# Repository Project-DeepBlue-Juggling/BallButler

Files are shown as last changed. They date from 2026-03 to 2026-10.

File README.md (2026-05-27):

# Ball Butler

An autonomous mobile robot that retrieves, stores, and throws balls to humans or other robots. Built around a 4-wheel swerve drive rover with onboard perception and a precision ball-throwing mechanism.

## Ball Butler V0 — Current State

The V0 thrower is **operational**. It accepts a target state (position and time) and executes a throw to hit that target. The mechanism was originally developed as part of the [Jugglebot](https://github.com/Project-DeepBlue-Juggling/Jugglebot) project and is now the foundation for the full Ball Butler system.

V0 is a deliberately simple, fixed-base machine — it predates the rover and is much less capable than the eventual mobile system described below. The version progression (V0 → V1+) is summarised in the comparison table at the end of this README.

**[CAD Model (Onshape)](https://cad.onshape.com/documents/b9a77ae444a199ae8fa4f0ef/w/58a21fff0c13c6549ee3697c/e/5104799fd810ebb1022a8885)**

### V0 mechanism (3 DoF, fixed-base)

- **Yaw** — unlimited rotation via a slip ring (no rewind required).
- **Pitch** — ~90° of travel: 0° = horizontal launch, 90° = vertical launch.
- **Linear axis** — a fast linear actuator provides the throwing motion itself.
- **Ball hopper** — manually loaded; a mechanical release drops one ball into the thrower each time a bumper is hit, so the thrower can reload itself once the hopper is filled.

### What works today

- Throwing to arbitrary commanded target states (position, time)
- Throw range ~2–4 m horizontal; launch height currently capped at ~50 cm by ceiling clearance during indoor testing
- Bumper-triggered single-ball release from the hopper
- Integration with Jugglebot as a ball-serving system

### What V0 does *not* do

- **No mobility** — V0 cannot move itself; it sits on a stand
- **No ball pickup** — the hopper is reloaded by hand
- **No catching** — V0 is throw-only. *No version of Ball Butler will catch balls.* The eventual rover-based system picks balls up off the ground after they land; it does not catch mid-air.

## Ball Butler V1+ — Planned System

The full Ball Butler is a standalone mobile robot — a substantial step up from V0 in every respect. V0 is essentially just the throwing subsystem on a stand; V1+ adds mobility, autonomous ball pickup, larger onboard storage, and a perception/navigation stack. V1+ comprises:

- **Rover platform** — 4-wheel swerve drive (8 DoF) for omnidirectional movement over sidewalks, curb cuts, grass, and gravel. Suspended wheels for terrain compliance.
- **Throwing mechanism** — evolved from the current thrower, mounted atop the rover.
- **Ball pickup** — a mostly-mechanical system to collect balls from the ground and feed them into onboard storage.
- **Ball storage** — onboard hopper carrying 5-10 balls (~70 mm, ~80 g each).
- **Navigation** — LiDAR and/or depth cameras for obstacle avoidance and path planning, teleoperated via a handheld controller with autonomous path smoothing.

### Key specs (targets)

| Parameter | Target |
|---|---|
| All-up mass | 25-35 kg |
| Top speed | 1.5-2 m/s |
| Obstacle clearance | Up to ~5-8 cm |
| Runtime | 1-2 hours |
| Drive motors | Hoverboard hub motors (x4) |
| Steering motors | BLDC with belt reduction (x4) |
| Motor controllers | moteus r4.11 (drive), moteus c1 (steering) |
| Compute | Jetson Orin Nano/NX |

## V0 vs V1+ at a Glance

| | **V0 (current, operational)** | **V1+ (planned)** |
|---|---|---|
| Throwing mechanism | 3 DoF (yaw / pitch / linear) | Evolved thrower atop rover (TBD architecture) |
| Yaw range | Unlimited (slip ring) | TBD |
| Pitch range | ~0–90° (horizontal → vertical) | TBD |
| Throw range | ~2–4 m horizontal | TBD |
| Catching | No | No (intentionally — no version will catch) |
| Mobility | None — fixed stand | 4-wheel swerve drive over outdoor terrain |
| Ball pickup | Manual (hand-loaded hopper) | Autonomous ground pickup |
| Hopper capacity | Small, bumper-triggered single-ball release | 5–10 balls |
| Perception / nav | None | LiDAR / depth cameras, teleop with autonomy |

## Development Approach

The rover platform is being developed **simulation-first** in MuJoCo before committing to hardware. The full simulation plan is documented in [`BB_rover_mujoco_plan.md`](BB_rover_mujoco_plan.md) and covers six phases:

1. ~~**Environment & tooling setup**~~ — MuJoCo scene, control loop, input handling **(done)**
2. ~~**Rigid chassis + swerve modules**~~ — driveable swerve drive on flat ground, inverse kinematics, teleoperation **(done)**
3. ~~**Suspension**~~ — spring-damper prismatic joints modelling the splined-shaft suspension concept, ride quality tuning **(done)**
4. ~~**Terrain & obstacle traversal**~~ — heightfield terrains (concrete, cracked sidewalk, curb cuts, grass, gravel), multi-terrain course, slope/tip-over analysis **(done)**
5. **Control stack** — motor controller modelling, swerve drive controller, velocity frame toggle (global/body), path following, odometry & state estimation
6. **Power & actuator analysis** — torque/speed/power logging, battery sizing, motor sizing validation
7. **Disturbance & robustness testing** — external forces, actuator failures, payload shift from throwing

The simulation will later extend to include Ball Butler integration (throwing disturbance on the rover), ball collection, hopper dynamics, and a simulated perception stack.

## Repository Structure

```
BallButler/
├── ball_butler_main/               # Thrower firmware (Arduino/Teensy)
│   ├── ball_butler_main.ino        #   Main sketch — state machine orchestration
│   ├── StateMachine.cpp/.h         #   State machine (BOOT → IDLE → THROWING → RELOADING)
│   ├── CanInterface.cpp/.h         #   CAN-FD communication with ODrives
│   ├── PitchAxis.cpp/.h            #   Pitch axis ODrive position control
│   ├── YawAxis.cpp/.h              #   Yaw axis brushed DC motor control
│   ├── HandPathPlanner.cpp/.h      #   Throw trajectory planning
│   ├── HandTrajectoryStreamer.h     #   Trajectory streaming to actuators
│   ├── Proprioception.cpp/.h       #   Central axis state repository
│   ├── Trajectory.h / TrajFrame.h  #   Trajectory and frame data structures
│   ├── RobotState.h                #   Robot state definitions
│   ├── BallButlerConfig.h          #   Thrower configuration parameters
│   ├── hardware_config.h           #   Auto-generated hardware constants (from Jugglebot config)
│   └── protocol_config.h           #   CAN protocol configuration
│
├── ball_butler_circuit_diagram/    # KiCad project — main electronics schematic
│   ├── *.kicad_sch                 #   Schematic sheets (main + Power and CAN)
│   ├── *.kicad_pcb                 #   PCB layout
│   ├── Ball_Butler_*.kicad_sym     #   Custom symbol libraries
│   └── Ball Butler Schematic*.pdf  #   Exported schematic PDFs
│
├── hand_sensor_pcb_rail/           # KiCad project — hand sensor PCB rail
│   ├── *.kicad_sch / *.kicad_pcb   #   Schematic and PCB layout
│   └── Production/                 #   Gerber files for manufacturing
│
├── zTesting/                       # Test scripts and experiments
│   ├── ball_butler_spacemouse.py   #   SpaceMouse teleoperation
│   ├── simulating_throw_types.py   #   Throw trajectory simulation
│   ├── yaw_inverse_kinematics.py   #   Yaw axis IK exploration
│   ├── calibrating_yaw_axis_with_mocap/  # MoCap-based yaw calibration
│   ├── sensored_hand_testing/      #   Hand sensor testing
│   ├── throw_testing/              #   Throw characterisation
│   └── ...                         #   Other hardware tests
│
├── BB_rover_mujoco_plan.md         # MuJoCo simulation plan for the rover platform
├── sim/                            # MuJoCo rover simulation (Phase 3 complete)
│   ├── main.py                    #   Simulation entry point — control loop, global-frame velocity, terrain support
│   ├── config.py                  #   Simulation parameters
│   ├── input_handler.py           #   Keyboard/gamepad → velocity commands
│   ├── data_logger.py             #   CSV data logging
│   ├── models/                    #   MJCF model files
│   │   ├── rover.xml              #   Shared rover body, actuators, sensors, contacts (included by scenes)
│   │   ├── scene.xml              #   Flat ground + Phase 2 test terrain (bumps, curb-cut ramp)
│   │   └── scene_terrain.xml      #   Multi-terrain course + slope analysis area (Phase 3)
│   ├── controllers/               #   Control algorithms
│   │   └── swerve_ik.py           #   Swerve drive inverse kinematics (4-wheel, with 180° flip optimisation)
│   ├── utils/                     #   Shared utilities (transforms, model helpers, sim runner, constants)
│   ├── terrains/                  #   Heightfield terrain generation
│   │   └── terrain_generator.py   #   Procedural grass/gravel heightfield generation
│   ├── tests/                     #   Simulation test scenarios (exit 1 on failure)
│   │   ├── test_suspension.py     #   Phase 2 headless suspension validation
│   │   └── test_terrain.py        #   Phase 3 terrain course + slope/tip-over validation
│   ├── logs/                      #   CSV data logs (gitignored)
│   └── requirements.txt           #   Python dependencies
│
├── bb_pitch_odrive_micro_config.json  # ODrive configuration for the pitch axis
└── .gitignore
```

### Planned additions

As the rover and full system are built out, expect these directories to appear:

```
BallButler/
├── rover/                          # Rover platform (planned)
│   ├── firmware/                   #   Motor controller firmware (moteus)
│   ├── config/                     #   Rover hardware configuration
│   └── cad/                        #   Mechanical design exports
│
├── navigation/                     # Navigation & perception (planned)
│   ├── local_planner/              #   Obstacle avoidance
│   └── odometry/                   #   Wheel odometry + IMU fusion
│
└── config/                         # Shared configuration (planned)
```

## Related Projects

- **[Jugglebot](https://github.com/Project-DeepBlue-Juggling/Jugglebot)** — the robot that Ball Butler (v0) was originally built to serve. Shared configuration files (e.g. `hardware_config.h`) are generated by Jugglebot and consumed by this repo.

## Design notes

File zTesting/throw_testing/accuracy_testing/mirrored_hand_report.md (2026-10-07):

# Mirrored hand experiment — 2026-10-05

The wrong hand side is a strong explanation for most of the original aiming
error, but does not by itself reproduce the remaining corrected feed bias.
This is offline analysis only: no operational code, geometry, affine, or feed
bias settings were changed.

## Method and sign

The production `bb_release_state` uses horizontal release position
`origin + (l*cos(pitch)-d)*(cos(yaw),sin(yaw)) + s*(-sin(yaw),cos(yaw))`.
The configured s is -105.65 mm. At yaw +90 degrees (throwing along +Y), that
puts the hand at +105.65 mm X. The user-reported physical left-hand position
therefore corresponds to **s = +105.65 mm in this code's convention**.

Keep the existing inverse-kinematics command, but change the physical forward
model to positive s. The complete trajectory shifts by
`211.3*(-sin(yaw), cos(yaw))` mm. Velocity, release z, flight time and pitch
are unchanged. This is an exact ballistic simulation under the isolated-error
hypothesis, not an approximation based on a particular flight duration.
Changing the solver sign changes yaw; its pitch/range solve uses s squared.

The script imports the production yaw solver and independently checks the
closed-form displacement against production 3D release states and gravitational
propagation: 12 checks, three horizontal targets, two heights, both signs.
All pass below 0.00001 mm. The historical June solver used the same yaw formula;
later changes to pitch selection do not change this isolated-error result.

## Archived data comparison

Inputs are the actual per-throw landing/target pairs retained in the provenance
of `throw_affine_correction.json` and `throw_affine_correction_v2_residual.json`.
The original raw QTM trajectories were not re-extracted or re-paired. Results
therefore inherit the original pairing and calibrated pose assumptions.
Statistics below weight each target cell equally, averaging repeated throws.

| Case | Throws / cells | Measured miss from target | Simulated miss from target | Measured–simulated distance |
|---|---:|---:|---:|---:|
| June 9, no affine | 41 / 21 | 194.6 mm | 211.3 mm | 42.3 mm |
| June 10, deployed affine | 32 / 16 | 30.9 mm | 48.2 mm | 51.2 mm |

All distance columns are mean Euclidean distances. The uncorrected prediction
matches the measured error direction within 9.18 degrees on average. Its
prediction residual RMS is 46.3 mm, versus 195.0 mm for the ideal unmirrored
model. This is substantial agreement with **no fitted physics parameters**,
but still leaves other geometry, pose, or execution errors unresolved.

For the corrected validation, the old affine is applied to each requested
target FIRST; yaw and physical landing are then recomputed. The residual-only
validation affine is not applied. The 51.2 mm prediction discrepancy demonstrates
that a mirror-only machine is not an adequate model of all remaining errors.

The mirror error rotates with yaw, so a single affine cannot represent its
inverse exactly over the whole workspace. Fitting an affine to the noiseless
mirror-only simulated grid and actually executing those corrected commands
still leaves 25.5 mm mean error (97.2 mm worst). This is an in-sample synthetic
demonstration of model mismatch, not a proposed calibration or a validation score.

## Two-ball feeds

Production `jugglebot_launch.py` defaults `apply_aim_correction` to true, despite
the node's standalone default being false. The deployed resource still contains
the June 9 matrix. Actual runtime overrides/install state are not available here.
`sites.py` sets the catch cup plane to 830 mm; the old grid was at 750 mm.
The isolated mirror shift itself is height-independent, but other errors
absorbed into the old affine need not be.

Using the **June 9 pose only**, and a global request (-40,0) mm (illustrative
of the default P1=-50 plus the 10 mm aim-toward-A displacement), the old affine
plus mirrored hand predicts **(-11.7,+28.2) mm** landing-minus-request.
At (0,0), it predicts (-15.0,+25.2) mm. These examples do not include today's
platform-to-mocap translation or BB calibration and are not predictions of the
current sitting. The recent code/probe record reports approximately
(+25.8,+27.3) mm for 14 October 4 L3 feeds: the X sign differs. Magnitude alone
is not sufficient to claim the current feed miss has been explained.

## Recommended next experiment

1. Correct the geometry sign to positive s and disable the existing affine
   together for an initial diagnostic batch. Keeping the old affine after
   correcting geometry would retain its compensation for the removed error.
2. With a freshly established BB pose, collect repeated isolated feeds at the
   actual columns catch target and height, plus a small surrounding grid. Use
   the same launch conditions and record actual commands, pose, affine state,
   feed bias state and raw ball tracks. Avoid stacking the separate columns
   feed bias during this diagnostic batch.
3. Compare measured landing-minus-request means and scatter. A useful initial
   design is 10–20 throws at the main feed point and at least five at each
   surrounding point, randomized/interleaved to expose drift. Choose spacing
   that covers the actual feed operating region; a 3x3 grid at 50 mm spacing
   is a reasonable starting proposal, subject to reachability.
4. Fit only the residual correction needed after geometry is right, then
   validate on a separate batch at the true catch plane. A local constant
   offset may suffice at one feed point; add affine terms only if spatial
   variation warrants them. Report repeatability separately from mean bias.

The 42.3 mm historical discrepancy is not a guaranteed post-fix accuracy:
changing yaw also changes how any yaw-dependent execution error acts.
The available evidence supports fixing a substantial physical-model error
before recalibrating, while expecting some recalibration to remain necessary.

## Reproduce

`python simulate_mirrored_hand.py --jugglebot E:/PDJ/Github/Jugglebot`

Outputs: `mirrored_hand_results.json` (all cells and metrics) and
`mirrored_hand_comparison.svg` (target/measured/simulated positions).
Requires numpy and a Jugglebot checkout, no ROS installation or hardware.

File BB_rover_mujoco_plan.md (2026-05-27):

# Swerve Drive Rover — MuJoCo Simulation Plan

## 1. Project Context

### 1.1 System Overview

The robot is an 8-DoF 4-wheel swerve drive rover carrying a ball-throwing robot (Ball Butler), a ball collection mechanism, and onboard ball storage. Each wheel module has two actuated axes: **drive** (wheel spin) and **yaw** (steering about the local vertical). This gives the rover full omnidirectional mobility — it can translate in any direction and rotate independently.

The rover is intended for outdoor use on sidewalks, curb cuts, grass, gravel, and smooth concrete, handling obstacles up to ~5–8 cm. It will be teleoperated via a nunchuck-style controller providing high-level velocity commands, with onboard LiDAR/depth cameras handling obstacle avoidance and path smoothing.

### 1.2 Physical Parameters (Working Estimates)

| Parameter | Estimate | Notes |
|---|---|---|
| Wheel type | Hoverboard hub motor | ~165 mm (6.5") diameter, pneumatic tire |
| Wheel mass | ~2.5 kg each | Including hub motor |
| Yaw motor | Small BLDC + belt reduction | ~5:1 ratio, ~0.3 kg motor + bracket |
| Chassis frame | Aluminium extrusion or plate | ~3–5 kg |
| Suspension travel | ~30–50 mm | Spring-damper per wheel |
| Payload (Ball Butler) | ~3–4 kg | ~350 mm diameter, ~450 mm tall |
| Ball pickup mechanism | ~2–3 kg | Mostly mechanical |
| Ball hopper (5–10 balls) | ~0.4–0.8 kg | Balls are ~70 mm, ~80 g each |
| Battery | ~3–5 kg | 36 V, 10–15 Ah Li-ion |
| Compute + sensors | ~1–2 kg | Jetson Orin + LiDAR/depth cameras |
| **All-up mass** | **~25–35 kg** | |
| Top speed | 1.5–2 m/s | Brisk walking pace |
| Wheel track / wheelbase | ~400–500 mm | TBD during chassis design |

### 1.3 Motor Controllers

| Axis | Controller | Qty | Notes |
|---|---|---|---|
| Drive (wheel spin) | moteus r4.11 | 4 | CAN-FD, 10–44 V, 100 A peak |
| Yaw (steering) | moteus c1 | 4 | CAN-FD, 10–51 V, 20 A peak |

### 1.4 Suspension Concept

The yaw motor is chassis-mounted (sprung mass). A keyed/splined shaft runs through the motor bore (or is belt-driven from the motor), supported by a linear ball spline bearing. A spring-damper acts between the chassis and the wheel fork, allowing the wheel to travel axially while the yaw motor transmits rotation through the spline. The drive motor (hoverboard hub) is unsprung, mounted directly to the wheel fork.

### 1.5 Payload — Ball Butler (Context Only)

Ball Butler is a ball-throwing mechanism mounted atop the rover. It is **throw-only** — no version of the robot catches balls; balls are picked up from the ground after they land. The current standalone version (V0) is a fixed-base, 3 DoF machine: unlimited yaw (slip ring), ~90° of pitch (0° horizontal to 90° vertical), and a fast linear axis providing the throwing motion itself. The on-rover variant will evolve from V0; for the purposes of this plan only its mass and approximate footprint matter.

The ball collection mechanism is a mostly-mechanical system that picks balls up off the ground and transfers them into an onboard hopper. The thrower draws from this hopper.

For simulation purposes, the Ball Butler and collection mechanism are modelled as a lumped mass in early phases and as articulated bodies in later phases.

---

## 2. Phase Summary

| Phase | Status | Summary |
|---|---|---|
| **0 — Environment & Tooling Setup** | [x] Complete | Set up MuJoCo Python project, flat ground plane, simulation loop, and gamepad/keyboard input. |
| **1 — Rigid Chassis + Swerve Modules** | [x] Complete | Build the MJCF model with 4 swerve modules, implement swerve drive inverse kinematics, and validate omnidirectional driving on flat ground. |
| **2 — Suspension** | [x] Complete | Add prismatic spring-damper joints modelling the splined-shaft suspension concept. Tune for ride quality over bumps and curb-cut ramps. |
| **3 — Terrain & Obstacle Traversal** | [x] Complete | Create heightfield terrains (concrete, cracked sidewalk, curb cuts, grass, gravel), build a multi-terrain course, and perform slope/tip-over analysis. |
| **4 — Control Stack** | [ ] Incomplete | Model motor controller dynamics, implement the full swerve drive controller with rate limiting and wheel coordination, add path following and odometry. |
| **5 — Power & Actuator Analysis** | [ ] Incomplete | Log per-motor torque/speed/power across terrain types and driving profiles. Size the battery and validate motor selection against simulation demands. |
| **6 — Disturbance & Robustness Testing** | [ ] Incomplete | Test external impulses, actuator failures, and payload disturbances (e.g. throwing reaction forces). Identify safety margins and degraded-mode behaviour. |

---

## 3. Simulation Objectives

1. **Validate the swerve drive kinematics** — confirm omnidirectional mobility, turning on the spot, and smooth trajectory following.
2. **Tune suspension parameters** — find spring/damper values that keep the payload stable while allowing the wheels to track uneven terrain.
3. **Test obstacle traversal** — curb cuts (up to ~50–80 mm ramps), sidewalk cracks, grass/gravel friction.
4. **Develop and validate the control stack** — swerve drive inverse kinematics, velocity control, and basic path following.
5. **Estimate power consumption** — torque and speed profiles across terrain types to size the battery.
6. **Explore failure modes** — what happens when a wheel loses contact, when the rover tips on a slope, when the yaw motor can't track fast enough.
7. **Provide a sim2real bridge** — produce a simulation accurate enough to transfer control parameters to hardware with minimal retuning.

---

## 4. Phased Implementation Plan

### Phase 0: Environment & Tooling Setup
**Duration:** 1–2 days
**Goal:** MuJoCo environment ready, basic rendering and control loop working.

**Tasks:**
- Set up a MuJoCo Python project (using `mujoco` package directly or via `mujoco-python-viewer` for interactive visualisation).
- Create a flat ground plane with realistic friction (concrete-like, mu ≈ 0.7–1.0).
- Establish the simulation loop structure: stepped physics, control callback, data logging.
- Set up a basic gamepad/keyboard input for manual driving (this becomes the nunchuck proxy).
- Decide on simulation timestep. MuJoCo default is 2 ms; this should be fine for a rover. The control loop can run at a lower rate (e.g., 50–100 Hz) inside the simulation.

**Deliverable:** An empty scene with a ground plane and a control loop that reads input and logs data.

**Status: COMPLETE** (2026-03-20)

**Implementation notes:**
- Using MuJoCo 3.6.0 native Python bindings with `mujoco.viewer.launch_passive` for interactive visualisation (no third-party viewer needed).
- Ground plane: 20x20 m, `condim="4"`, friction `0.9 0.005 0.001` (tangential / torsional / rolling). This matches "good concrete" and provides the lateral grip swerve drive needs.
- Physics at 500 Hz (2 ms), control callback at 50 Hz (decimation=10), render target 60 FPS.
- Input via pygame: keyboard (WASD+QE) and optional gamepad (left stick = translate, right stick = rotate). Gamepad overrides keyboard when active.
- CSV data logger writes timestamped records (sim_time, wall_time, cmd_vx, cmd_vy, cmd_omega) to `sim/logs/`. Extends easily for motor/sensor data in later phases.
- Pygame requires a display surface for keyboard events even though rendering is handled by MuJoCo's viewer — a 1x1 hidden window is created for this purpose.

**Observations for later phases:**
- `solref` and `solimp` are set to safe defaults (`0.02 1` / `0.9 0.95 0.001`). These will likely need per-terrain tuning in Phase 3 — the current values prioritise stability over realism.
- MuJoCo 3.6.0 ships with `Euler` and `implicit`/`implicitfast` integrators. Stiff suspension springs in Phase 2 may benefit from switching to `implicitfast` if Euler causes oscillation at 2 ms timestep.
- The passive viewer's camera can be set programmatically but the user can also orbit/zoom freely. For Phase 1 teleoperation, the tracking camera following the chassis CoM should work well.

---

### Phase 1: Rigid Chassis + Swerve Modules (No Suspension)
**Duration:** 1–2 weeks
**Goal:** A driveable swerve drive rover on flat ground.

**Tasks:**

**1.1 — MJCF Model of the Chassis**
- Model the chassis as a single rigid body (box or simplified mesh) with appropriate mass and inertia.
- Attach 4 swerve module "mounts" at the corners. Initially, these are just fixed attachment points.

**1.2 — Swerve Module Model**
- Each module has two revolute joints:
  - **Yaw joint** — vertical axis, connects chassis to wheel fork. Actuated (position or velocity controlled).
  - **Drive joint** — horizontal axis (wheel spin axis), connects fork to wheel. Actuated (velocity controlled).
- The wheel is a cylinder or sphere-capped cylinder with appropriate radius (82.5 mm), width (~50 mm), and mass (~2.5 kg).
- MuJoCo contact: use `condim="3"` or `condim="4"` for the wheel-ground contact to get lateral friction (critical for swerve drive). Tune `friction`, `solref`, and `solimp` to approximate pneumatic rubber on concrete.

**1.3 — Swerve Drive Inverse Kinematics**
- Implement the standard swerve drive IK: given a desired chassis velocity (vx, vy, omega), compute the required wheel speed and yaw angle for each of the 4 modules.
- Handle the "180° flip" optimisation (if the target angle is >90° from current, reverse wheel direction and use the supplementary angle).
- Implement as a Python controller that runs in the simulation loop.

**1.4 — Basic Teleoperation**
- Map gamepad/keyboard input to (vx, vy, omega) commands.
- Feed through the swerve IK to actuator commands.
- Drive the rover around on flat ground. Verify omnidirectional motion, rotation, and combined translation+rotation.

**Validation criteria:**
- The rover can translate in any direction without rotating.
- The rover can rotate in place.
- The rover can follow a circular arc.
- No wheel scrub (wheels point in the correct direction during motion).

**Status: COMPLETE** (2026-03-20)

**Implementation notes:**
- **Chassis body:** 480×480×80 mm box (10 kg) with a freejoint. Centre at z=0.21 m, providing 5 mm clearance above wheel tops.
- **Lumped payload:** 300 mm diameter × 200 mm tall cylinder (8 kg) atop the chassis, with `contype="0" conaffinity="0"` so it doesn't participate in contacts. Total model mass: 30 kg.
- **Swerve modules:** Each consists of a yaw hinge joint (vertical axis) → fork body (0.5 kg) → drive hinge joint (horizontal axis) → wheel cylinder (82.5 mm radius × 50 mm wide, 2.5 kg). Modules at ±225 mm in x and y from chassis centre (450 mm track/wheelbase).
- **Wheel contact:** `condim="4"`, friction `1.0 0.005 0.001` — high tangential grip, low torsional and rolling friction. 8 contact points per frame (2 per wheel due to cylinder-plane contact).
- **Contact exclusions:** All chassis↔fork and chassis↔wheel contacts are excluded via `<exclude>` pairs. This is essential — without these, the wheel geoms collide with the chassis geom (they are geometrically close) and generate ~9000 N parasitic forces that prevent the rover from moving.
- **Yaw actuators:** `<position>` with kp=50 N·m/rad, torque limit ±10 N·m. Joint damping 2.0 N·m·s/rad for stability.
- **Drive actuators:** `<velocity>` with kv=10 N·m·s/rad, torque limit ±30 N·m. Joint damping 0.05 N·m·s/rad.
- **Swerve IK:** Standard 4-wheel swerve inverse kinematics in `sim/controllers/swerve_ik.py`. Includes 180° flip optimisation and a speed deadband (0.01 m/s) to prevent yaw jitter at rest.
- **Teleoperation:** Keyboard tap-based control via MuJoCo viewer key callback (arrow keys, comma/period, space) and optional gamepad. Feeds through swerve IK at 50 Hz.
- **Data logging:** Extended from Phase 0 with per-module yaw command/position, drive command/velocity, and chassis x/y/heading.
- **Sensors:** IMU (accelerometer + gyro) at chassis centre, 4× yaw position sensors, 4× drive velocity sensors.

**Validation results (headless, scripted tests):**
- Forward at 1.0 m/s: tracked at 0.994 m/s with near-zero lateral drift. 2.92 m in 3 s.
- Strafe at 0.5 m/s: tracked at 0.497 m/s. 1.49 m in 3 s.
- Rotate in place at 1.0 rad/s: achieved 171.6° in π seconds (slight undershoot from rotational inertia). Translation drift <15 mm.
- Circular arc (vx=0.5, omega=0.5, R=1.0 m): closed a full circle with <0.1 m closure error. Each wheel showed distinct yaw angles appropriate for the arc geometry (inner wheels steer more).

**Observations for later phases:**
- **Yaw actuator torque limit (±10 N·m) may be tight.** During combined translation+rotation, the yaw actuators reach ~5 N·m. Aggressive manoeuvres or higher friction surfaces in Phase 3 could saturate them. Monitor and increase if needed.
- **Drive actuator kv=10 and forcerange=±30 N·m are generous for flat ground.** The velocity tracking is very accurate (<1% error at 1 m/s). On terrain with higher resistance (gravel, slopes), these may need increasing — or the saturation behaviour itself becomes interesting for Phase 5 power analysis.
- **Wheel-ground contact model is adequate for flat concrete** but the cylinder-plane contact produces 2 contact points per wheel (at the cylinder edges), not a continuous contact patch. For Phase 3 terrain work, consider whether this affects lateral force fidelity on rough surfaces.
- **The 180° flip optimisation works but has a discontinuity** at exactly ±90° from current angle. In practice this hasn't caused issues because the control rate (50 Hz) prevents the target angle from changing that fast. Phase 4's rate-limited yaw controller will handle this more gracefully.
- **Chassis height (z=0.21 m centre, 0.17 m bottom) leaves only ~87.5 mm ground clearance** (to the bottom of the fork geom). This is within the 5–8 cm obstacle spec but tight. Phase 2 suspension will add ~25 mm of travel downward, reducing static clearance further. Worth tracking during suspension design.
- **Drive actuator `ctrlrange` silent clamping.** The drive velocity actuators have `ctrlrange="-30 30"` (rad/s). At max speed (2 m/s) a single wheel needs ~24.2 rad/s, but during aggressive combined translation+rotation, corner wheels can exceed 30 rad/s. MuJoCo silently clamps the ctrl signal, so one wheel loses proportionality without the others scaling down. Phase 4's wheel speed coordination (scaling all wheels when any exceeds the limit) should address this.
- **Body-frame velocity commands cause circular arcs during combined translation+rotation.** *(Resolved post-Phase 3.)* The swerve IK correctly takes body-frame inputs, but when the chassis is spinning, "forward" rotates with it. A global-to-body-frame rotation transform was added to the control loop (`main.py`) so that velocity commands from the input handler are now interpreted in the world frame. The IK itself is unchanged. See Phase 4 for the planned body/global frame toggle.

---

### Phase 2: Suspension
**Duration:** 1–2 weeks
**Goal:** Add the spring-damper suspension and validate ride quality.

**Tasks:**

**2.1 — Prismatic Joint for Suspension**
- Replace the fixed yaw-joint-to-chassis connection with a **prismatic (slide) joint** along the local vertical axis, plus the yaw revolute joint.
- Joint order (from chassis outward): prismatic (suspension travel) → revolute (yaw) → revolute (drive) → wheel body.
  - *Or*, if modelling the spline concept faithfully: revolute (yaw, chassis-mounted) → prismatic (axial slide) → fork body → revolute (drive) → wheel.
  - The second ordering is more physically accurate. The yaw motor is on the chassis and drives rotation; the spline shaft slides axially below it.
- Limit the prismatic joint range to ±25 mm (50 mm total travel) or similar.

**2.2 — Spring-Damper Tuning**
- Apply a spring + damper to the prismatic joint. MuJoCo supports this natively via joint `stiffness` and `damping` attributes, or via a custom force in the control callback.
- Starting point: for ~7 kg per corner (28 kg / 4), a natural frequency of ~3–5 Hz gives spring constant k ≈ 2500–7000 N/m. Damping ratio ~0.3–0.5 (underdamped for comfort, enough to prevent oscillation).
- Create a flat ground with small bumps (5–10 mm sine wave) and a step (50–80 mm ramp) to test.

**2.3 — Validation**
- Drive over bumps at various speeds. Log chassis pitch/roll/heave.
- Drive over a curb-cut ramp (~50–80 mm rise over ~500 mm). Verify all 4 wheels maintain contact.
- Check that suspension bottoming-out is handled (joint limits + contact).

**Validation criteria:**
- Chassis remains approximately level over small bumps.
- All wheels maintain ground contact over the curb-cut ramp.
- No excessive oscillation after a bump.

**Status: COMPLETE** (2026-03-20)

**Implementation notes:**
- **Kinematic chain per module (physically accurate):** yaw hinge (chassis-mounted) → prismatic slide (spline shaft) → fork body → drive hinge (hub motor) → wheel. This adds a `XX_yaw_body` between the chassis and fork, with the yaw motor as sprung mass (0.3 kg). Fork mass reduced from 0.5 kg to 0.2 kg (total per-module mass unchanged at 3.0 kg).
- **Integrator switched from `Euler` to `implicitfast`** for better stability with spring-damper joints. No performance cost; prevents potential oscillation at 2 ms timestep.
- **Suspension parameters:**
  - Stiffness: 3600 N/m (natural frequency ~4.4 Hz for 4.8 kg sprung mass per corner).
  - Damping: 100 N·s/m (damping ratio ζ ≈ 0.39 — underdamped but well-behaved).
  - Travel: ±25 mm (50 mm total).
  - `springref = -0.013 m` — preloads the spring so that the static equilibrium sits near q=0, giving symmetric travel in both directions.
- **Contact exclusions updated:** New body hierarchy requires exclusions for non-adjacent bodies (chassis↔fork, chassis↔wheel, yaw_body↔wheel). Parent-child exclusions are handled automatically by MuJoCo.
- **Suspension sensors:** 4× `jointpos` sensors added for per-module displacement logging.
- **Test terrain added to scene.xml:**
  - 6 small bumps (5–10 mm tall, 40 mm wide) spaced 0.4 m apart along the x-axis (x=3.0..5.0 m).
  - A curb-cut ramp at x=6.5..8.5 m: inclined slab (8°) → flat top (70 mm elevation, 500 mm long) → inclined slab down.
- **Logging extended** with per-module suspension displacement, chassis z (heave), pitch, and roll.

**Validation results (headless, scripted tests):**
- **Static settling:** Suspension settles at +0.08 mm per corner (design target: 0 mm). Chassis sag: 0.3 mm. Zero residual oscillation after 3 s — damping is effective.
- **Bump traversal (1.0 m/s):** Chassis heave range: 13.9 mm over 5–10 mm bumps. Pitch oscillation: ±1.4°. Roll: negligible (±0.01°, bumps are full-width). Suspension travel: ±11 mm (well within ±25 mm limits). Velocity tracking: 0.975 m/s (target 1.0).
- **Curb-cut ramp (0.5 m/s):** Ramp traversed successfully. Chassis z on flat top: 0.261 m (vs expected 0.280 m — the 19 mm deficit is suspension compression under transitional loading). Suspension travel reaches ±23 mm (92% of limit, see observations below). Pitch excursion: ±13° during ramp transitions.
- **Velocity tracking:** Forward: 0.975 m/s (Phase 1: 0.994). Strafe: 0.462 m/s (Phase 1: 0.497). Rotation: 171.6° in π s (identical to Phase 1). Suspension does not degrade swerve drive performance.

**Observations for later phases:**
- **Suspension nearly bottoms out on the 70 mm curb-cut ramp.** Peak travel reaches 23 mm of the 25 mm limit (92%). The 70 mm ramp is at the upper end of the design spec (50–80 mm), and the suspension just barely handles it. Options for Phase 3: (a) increase travel to ±30 mm if chassis clearance allows, (b) stiffen springs (reduces ride quality on small bumps), or (c) accept that 70+ mm obstacles require slower approach speeds. This is a real design constraint worth tracking during hardware development.
- **Pitch excursion during ramp is ±13° — significantly more than the 8° ramp angle.** This is because only 2 wheels are on the ramp at a time (the 450 mm wheelbase means the front and rear axles encounter the ramp ~0.5 s apart at 0.5 m/s). The chassis pitches as the front wheels climb while the rear are still flat (and vice versa). This dynamic overshoot is expected but worth considering for payload stability — Ball Butler's throwing mechanism may need to account for or wait out these transients.
- **Static sag is nearly zero (0.3 mm)** thanks to the `springref` preload. This validates the approach of computing springref from the sprung mass and stiffness. If the payload mass changes significantly (e.g., hopper full vs empty — ~0.8 kg difference), the sag shift is only ~2 mm, well within tolerance.
- **Velocity tracking is slightly lower with suspension than Phase 1** (0.975 vs 0.994 m/s forward). This ~2% reduction is from energy being absorbed by suspension motion. This is physically realistic and not a concern.
- **The `implicitfast` integrator works well.** No oscillation or instability observed at 2 ms timestep with k=3600 N/m springs. This is expected — the suspension's natural frequency (~4.4 Hz) is far below the 500 Hz physics rate. The Euler integrator would likely also work fine here, but `implicitfast` provides a safety margin for Phase 3 when stiffer terrain contacts may interact with the suspension.

---

### Phase 3: Terrain & Obstacle Traversal
**Duration:** 1–2 weeks
**Goal:** Validate the rover on realistic outdoor terrain.

**Tasks:**

**3.1 — Terrain Models**
- Create several terrain types as MuJoCo heightfields or meshes:
  - **Smooth concrete** — flat, high friction (mu ~0.8–1.0).
  - **Cracked sidewalk** — flat with 5–15 mm step discontinuities.
  - **Curb cut** — a 50–80 mm ramp at ~8–10° slope.
  - **Grass** — slightly uneven heightfield (±10–20 mm noise), lower friction (mu ~0.5–0.7), possibly higher rolling resistance.
  - **Gravel** — rougher heightfield (±15–30 mm), moderate friction, high rolling resistance.
- For each terrain, tune MuJoCo contact parameters (friction, solref, solimp) to approximate real behaviour.

**3.2 — Multi-Terrain Course**
- Stitch terrains together into a continuous course: concrete → curb cut → sidewalk → grass → gravel → back to concrete.
- Drive the course manually and automatically (straight line, then with turns).

**3.3 — Slope and Tip-Over Analysis**
- Add slopes (5°, 10°, 15°) and drive across them (lateral and longitudinal).
- Log the centre of mass position relative to the support polygon. Identify the tip-over angle.
- This informs maximum safe operating slope and whether the CoG (with Ball Butler on top) is too high.

**Validation criteria:**
- Successful traversal of the multi-terrain course at 1 m/s.
- No tip-over on slopes ≤ 10°.
- Identified maximum safe slope angle.

**Status: COMPLETE** (2026-03-20)

**Implementation notes:**
- **Terrain course** (`scene_terrain.xml`): 30 m multi-terrain course along the +x axis with 6 distinct terrain sections, plus a slope analysis area at y=5 m offset.
- **Course layout:** concrete (x=-2..4) → curb cut UP (70 mm, ~8°) → cracked sidewalk (z=70 mm base + 5–15 mm steps) → curb cut DOWN → grass (heightfield ±15 mm) → gravel (heightfield ±25 mm) → concrete (x=24..30).
- **Heightfield generation** (`terrains/terrain_generator.py`): Procedural noise generation at 20 mm grid spacing (301×151 grid per heightfield). Grass uses 10 iterations of smoothing for low-frequency undulations; gravel uses 4 iterations for higher-frequency texture. Edge tapering blends to z=0 at heightfield boundaries for smooth terrain transitions.
- **Contact parameters tuned per terrain type:**
  - Concrete: friction 0.9, default solref (0.02 1).
  - Sidewalk: friction 0.85 (slightly weathered).
  - Grass: friction 0.55, rolling friction 0.003, solref 0.03 1.2 (softer, slightly overdamped contact).
  - Gravel: friction 0.7, rolling friction 0.005, solref 0.015 1.5 (moderate grip, high rolling resistance, more damped contact).
- **Slope analysis area:** Five slopes at 5°, 10°, 15°, 20°, 25° (each 3 m × 3 m × 1 m thick tilted box), positioned along +x at y=5 m. Flat landing pads (2 m long) at the top of each slope to prevent cliff-edge drop-offs. Flat ground slab for approach.
- **Interactive use:** `python main.py --terrain` loads the terrain course scene. The original Phase 2 scene (`python main.py`) is unchanged.

**Validation results (headless, scripted tests):**
- **Full terrain course at 1.0 m/s:** Successfully traversed all 6 terrain sections. Distance covered: 29.66 m in 30 s = 0.989 m/s average speed.
  - Concrete: nominal (pitch ±5.7°, susp max 19.9 mm during initial bump transitions).
  - Curb cut UP: pitch ±9.4° (dynamic overshoot from 8° ramp), suspension max 12.3 mm.
  - Cracked sidewalk: very stable (pitch ±3.7° over 5–15 mm steps, roll ±0.05°, susp max 10.2 mm).
  - Curb cut DOWN: pitch +8.7° (reverse of UP), suspension max 7.7 mm.
  - Grass: mild roll ±0.32° from heightfield undulations. Lower friction (0.55) did not cause measurable slip at 1 m/s. Suspension max 7.1 mm.
  - Gravel: more pronounced pitch ±7.4° and roll ±0.80° from rougher heightfield. Suspension max 11.9 mm. Higher rolling friction (0.005) did not noticeably slow the rover at 1 m/s.
  - Concrete (return): smooth, pitch transient from gravel → concrete transition.
- **Slope climbing at 0.5 m/s:**
  - 5°: climbed cleanly (0.262 m height, target 0.261 m).
  - 10°: reached the top (0.524 m, target 0.521 m) but **flipped at the slope-to-landing-pad crest transition** (pitch excursion to 89.5°).
  - 15°: reached the top (0.807 m, target 0.776 m) but also flipped at the crest.
  - 20°: climbed cleanly (0.949 m, target 1.026 m — reached 92% of target height).
  - 25°: climbed cleanly (1.172 m, target 1.268 m — 92%). Pitch excursion ±56° but no full flip.
  - Maximum climbable angle: 25° (with traction available on concrete-friction slopes). The 10° and 15° crest flips are speed-dependent — the rover crests with enough momentum to pitch forward off the landing pad.
- **Tip-over analysis (stationary):**
  - Longitudinal: stable up to 25° (margin 149.6 mm at 25°). The support polygon is wide enough in the forward direction.
  - Lateral: stable up to 15° (margin 185.2 mm). **Flipped at 20°** (roll 160°).
  - Overall maximum safe slope: **15°** (limited by lateral stability due to the tall Ball Butler payload raising the CoG).

**Post-Phase 3 refactoring:**
- **Rover MJCF extracted to `models/rover.xml`** and included via `<include>` in both scene files. Chassis body, contact exclusions, actuators, and sensors are now defined once.
- **Shared utility module `sim/utils/`** created, consolidating duplicated code: `quat_to_euler`, `get_ids`, `step_with_control`, model loaders, and joint/actuator name constants. Both test files and `main.py` now import from `utils/`.
- **Global-frame velocity commands** added to `main.py`. Input handler commands (vx, vy) are rotated into the body frame using the current chassis heading before feeding into the swerve IK. This fixes the circular-arc behaviour during combined translation+rotation.
- **Test exit codes** added — both test scripts now call `sys.exit(1)` on failure for CI compatibility.
- **`tests/__init__.py`** added for proper package structure.

**Observations for later phases:**
- **Lateral stability is the binding constraint for slope operation.** The rover is stable to 25° longitudinally but only 15° laterally. The 450 mm track width and high CoG (weighted average ~272 mm due to the 8 kg payload at 350 mm) give a theoretical lateral tip-over angle of ~39°, but the dynamic margin is lower. The ~15° practical limit is well above the 10° design requirement but worth tracking as payload mass/height changes.
- **Crest transitions are the dominant hazard during slope climbing, not the slope itself.** The rover can climb 25° slopes with adequate traction, but the pitch transient at the slope-to-flat transition causes flips at 10° and 15° when approaching at 0.5 m/s. Phase 4's controller should implement speed reduction near slope crests (detectable via pitch rate). Alternatively, a pitch-rate-limited velocity controller would naturally slow down as the crest approaches.
- **Grass and gravel friction models are plausible but need hardware validation.** The chosen values (mu=0.55 grass, mu=0.7 gravel) are consistent with published friction coefficient ranges, but the heightfield surface profiles are procedurally generated. Real terrain has spatially correlated features (e.g., tyre tracks, drainage channels) that the random noise model doesn't capture. The key finding — that neither terrain type causes significant slip at 1 m/s — is robust to moderate friction variation since the swerve drive operates well below the friction limit during straight-line driving.
- **Sidewalk crack traversal is benign.** The 5–15 mm step discontinuities produce only ±3.7° pitch and 10.2 mm suspension use. This is well within the suspension's ±25 mm travel. Real sidewalk cracks may include wider gaps (which could trap a wheel) — the current model uses solid raised slabs without gaps.
- **Suspension stays within limits across all terrain types in the course.** Peak usage was 19.9 mm (on concrete transitions) vs the 25 mm limit. The Phase 2 concern about near-bottoming on curb cuts (23 mm) is less acute in Phase 3 because the curb cut ramp design is slightly different (smoother transitions at entry and exit).
- **The gravel contact model (solref 0.015 1.5) produces more pitch/roll than grass** despite having higher friction (0.7 vs 0.55). This is because the ±25 mm heightfield roughness is the dominant effect, not the friction. The stiffer contact (lower solref time constant) also means the gravel "pings" the suspension harder than the softer grass contact.

---

### Phase 4: Control Stack
**Duration:** 2–3 weeks
**Goal:** Implement and tune the full control hierarchy.

**Tasks:**

**4.1 — Low-Level Motor Controllers**
- Model the moteus controllers as velocity/position loops with realistic bandwidth.
  - Drive motors: velocity control with ~50–100 Hz bandwidth.
  - Yaw motors: position control with ~20–50 Hz bandwidth (belt reduction limits speed).
- Add actuator dynamics: motor time constants, torque limits, current limits. Use MuJoCo's actuator `dyntype` and `gaintype` or implement in the control callback.

**4.2 — Swerve Drive Controller (Mid-Level)**
- Velocity command → swerve IK → individual motor commands.
- Add rate limiting on yaw angle changes to respect the physical yaw speed (~1 rev/s = 360°/s, so any angle is reachable in <0.5 s).
- Add wheel speed coordination: if one wheel can't reach its target speed (e.g., inner wheel during a tight turn), scale all wheels proportionally.
- Add a **velocity frame toggle** (global vs body frame). Global frame is the current default — velocity commands are interpreted as world x/y and rotated into the body frame using the chassis heading each control step. Body frame interprets commands relative to the chassis orientation (more natural for "drive like a car" control). Both modes are useful: global frame is better for waypoint-following and "move to a position while facing a target"; body frame is more intuitive for manual gamepad driving. The toggle should be exposed as both a keyboard shortcut in the viewer and a config option.

**4.3 — Path Following (High-Level)**
- Implement a simple pure-pursuit or Stanley controller that tracks a sequence of waypoints.
- The "nunchuck" input generates a velocity command; the path follower handles smoothing and obstacle avoidance at a coarse level.
- This is a placeholder for the full autonomy stack (LiDAR SLAM + local planner) but validates the control interface.

**4.4 — Odometry & State Estimation**
- Compute rover odometry from wheel encoder feedback (motor joint positions/velocities).
- Compare with ground truth from MuJoCo. Quantify drift over distance.
- Optionally add an IMU sensor in MuJoCo and fuse with wheel odometry (EKF or complementary filter).

**Validation criteria:**
- The rover follows a 10 m waypoint path with <0.2 m cross-track error on flat ground.
- Odometry drift is <5% over 50 m on flat concrete.
- The controller handles transitions between translation and rotation smoothly.

---

### Phase 5: Power & Actuator Analysis
**Duration:** 1 week
**Goal:** Extract torque/speed/power data to inform hardware sizing and battery selection.

**Tasks:**

**5.1 — Data Logging**
- Log per-motor torque, speed, and power (τ × ω) at each timestep across all terrain types.
- Log total power draw (sum of all motors) over representative driving profiles:
  - Cruising at 1.5 m/s on flat concrete.
  - Navigating a mixed terrain course.
  - Turning on the spot.
  - Climbing a curb cut.

**5.2 — Analysis**
- Compute peak and RMS torque per motor, per terrain type.
- Compute average and peak power draw per driving profile.
- Estimate battery life: (battery capacity in Wh) / (average power draw in W) = hours.
- Verify that the hoverboard motors and moteus controllers are within their continuous ratings for typical use.

**5.3 — Motor Sizing Validation**
- Compare the simulation torque/speed requirements against the hoverboard motor specs.
- Check that the yaw motor + 5:1 belt reduction provides sufficient torque for on-the-spot rotation on the highest-friction surface.

**Deliverable:** A table mapping driving scenarios to power draw, with a battery sizing recommendation.

---

### Phase 6: Disturbance & Robustness Testing
**Duration:** 1 week
**Goal:** Understand failure modes and safety margins.

**Tasks:**

**6.1 — External Disturbances**
- Apply impulse forces to the chassis (simulating a bump or push) and verify the rover recovers.
- Apply a sustained lateral force (simulating wind or a slope) and check steady-state tracking error.

**6.2 — Actuator Failures**
- Disable one drive motor and verify the rover can still move (degraded mode — 3-wheel swerve).
- Lock one yaw motor and verify the rover can still navigate (effectively a caster on that corner).
- Saturate a yaw motor (it can't keep up with commanded angle) and observe the trajectory error.

**6.3 — Payload Shift**
- Move the payload CoG off-centre (simulating uneven ball loading) and check stability.
- Add a dynamic payload disturbance (simulating Ball Butler's throwing motion — a ~0.5 kg mass moving at ~5 m/s for ~0.1 s).

**Validation criteria:**
- The rover recovers from a 50 N impulse within 1 second.
- The rover remains controllable with one failed drive motor.
- Ball Butler throwing does not cause the rover to tip or significantly deviate from its path.

---

## 5. MJCF Model Structure (Sketch)

This is a high-level outline of the XML structure. Details will be refined during implementation.

```
worldbody
├── light, camera
├── ground plane (geom or heightfield)
├── test terrain (bumps, curb-cut ramp)
│
└── chassis (body, mass ~15-20 kg)
    ├── chassis geom (box or mesh)
    ├── payload mass (lumped Ball Butler + hopper + sensors)
    │
    ├── front-left module
    │   ├── yaw joint (revolute, vertical axis) — actuated
    │   ├── yaw body (motor + bracket, ~0.3 kg, sprung)
    │   │   ├── suspension joint (prismatic, vertical) — spring/damper
    │   │   └── fork body (~0.2 kg, unsprung)
    │   │       ├── drive joint (revolute, horizontal) — actuated
    │   │       └── wheel body (cylinder, ~2.5 kg, unsprung)
    │   │           └── wheel geom (contact)
    │
    ├── front-right module (mirror of front-left)
    ├── rear-left module
    └── rear-right module

actuator
├── 4× yaw actuators (position control)
└── 4× drive actuators (velocity control)
    (suspension is passive — spring/damper on prismatic joint)

sensor
├── chassis IMU (accelerometer + gyro)
├── 4× yaw joint position sensors
├── 4× drive joint velocity sensors
├── 4× suspension joint position sensors
└── (optional) rangefinder for ground clearance
```

---

## 6. Key MuJoCo Modelling Decisions

### 6.1 Wheel-Ground Contact
This is the single most important tuning parameter for a swerve drive simulation. The wheels need to grip laterally (no sliding) while allowing rolling. Key settings:
- `condim="4"` — enables tangential friction in both directions plus torsional friction.
- `friction="1.0 0.005 0.001"` — high tangential, low torsional and rolling friction.
- Tune `solref` and `solimp` for the contact stiffness/damping to avoid instability at the simulation timestep.

### 6.2 Actuator Modelling
- **Drive motors:** Velocity-controlled with torque limits. Use `<velocity>` actuator with `ctrlrange` and `forcerange` to model the hoverboard motor's torque-speed curve.
- **Yaw motors:** Position-controlled with velocity limits. Use `<position>` actuator with `kp` gain and `forcerange` for torque limit. The `kv` gain provides damping.

### 6.3 Simulation Timestep
- Start with 2 ms (500 Hz). If contact stability is an issue with the small suspension springs, reduce to 1 ms.
- Control loop at 50–100 Hz (every 10–20 sim steps).

### 6.4 What to Ignore (Initially)
- Electrical dynamics (motor inductance, controller bandwidth) — model as ideal torque sources initially.
- Battery voltage sag — assume constant bus voltage.
- Thermal effects — ignore motor heating.
- Sensor noise — add in Phase 4 if needed.
- Aero drag — negligible at 2 m/s.

---

## 7. Future Work — Ball Butler Integration

These items are not part of the initial simulation phases but represent the natural extension once the rover platform is validated.

### 7.1 Ball Butler Model
- Model the Stewart platform as a 6-DoF parallel mechanism atop the rover chassis.
- Include the linear throwing axis.
- Apply the existing Ball Butler kinematics and dynamics models.
- Simulate throwing while the rover is stationary and while moving — quantify the disturbance to the rover.

### 7.2 Ball Collection Mechanism
- Model the pickup mechanism as an actuated linkage or conveyor at the front/side of the rover.
- Simulate the rover driving toward a ball on the ground, collecting it, and transferring it to the hopper.
- This requires modelling the ball as a free body with appropriate contact properties.

### 7.3 Ball Storage (Hopper)
- Model the hopper as a container with 5–10 balls as free bodies.
- Simulate the effect of ball shifting on rover stability (dynamic CoG changes).
- Model the feed mechanism from hopper to Ball Butler.

### 7.4 Full Mission Simulation
- Combine rover navigation, ball collection, and ball throwing into a complete mission loop.
- The rover drives to a ball, picks it up, drives to a throwing position, and Ball Butler throws it.
- Validate that the full system works end-to-end in simulation before committing to hardware.

### 7.5 Perception Stack (Sim-Only)
- Add simulated LiDAR or depth camera sensors in MuJoCo.
- Feed sensor data to a local planner (e.g., DWA or TEB planner).
- Test the nunchuck → velocity command → local planner → swerve controller pipeline in sim.

---

## 8. Estimated Timeline

| Phase | Duration | Cumulative |
|---|---|---|
| Phase 0 — Environment setup | 1–2 days | 1–2 days |
| Phase 1 — Rigid chassis + swerve | 1–2 weeks | ~2 weeks |
| Phase 2 — Suspension | 1–2 weeks | ~4 weeks |
| Phase 3 — Terrain & obstacles | 1–2 weeks | ~6 weeks |
| Phase 4 — Control stack | 2–3 weeks | ~8 weeks |
| Phase 5 — Power analysis | 1 week | ~9 weeks |
| Phase 6 — Robustness testing | 1 week | ~10 weeks |

**Total estimated time to a validated simulation: ~10 weeks** (working part-time alongside other projects).

Phases 1–3 are the highest priority — they answer the fundamental question of whether the physical platform concept works. Phases 4–6 refine the design and prepare for hardware.

---

## 9. Open Questions

1. **Wheel track and wheelbase dimensions** — these determine the turning radius, tip-over stability, and overall footprint. Need to balance compactness (for sidewalks) with stability (tall CoG from Ball Butler).
2. **Hoverboard motor internal friction / cogging** — may need measurement to model accurately. Cogging torque can be significant at low speeds.
3. **Suspension preload** — with the uneven weight distribution (Ball Butler is offset from centre?), may need adjustable preload per corner.
4. **Yaw belt reduction backlash** — timing belts have very low backlash, but it's worth modelling if yaw precision matters for path tracking.
5. **Tyre model fidelity** — MuJoCo's contact model is good but not a dedicated tyre model. For accurate lateral force prediction during swerve, may need to compare against a Pacejka-like tyre model or validate against hardware early.

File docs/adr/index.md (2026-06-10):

# Architecture Decision Records

This directory holds **Architecture Decision Records (ADRs)** for the Ball Butler
— short documents that capture a single significant, hard-to-reverse decision:
the context, the options weighed, the choice, and its consequences.

Modelled on the [Jugglebot ADRs](https://github.com/Project-DeepBlue-Juggling/Jugglebot/tree/main/docs/adr).
See the repo-root [DOCUMENTATION_GUIDE.md](../../DOCUMENTATION_GUIDE.md) for how
ADRs relate to the logbook (the logbook records *what happened*; an ADR records
*why a structural choice was made*).

## When to write an ADR

Write one when a decision is **structural and costly to reverse** — a transport
choice, a frame/convention, a hardware split, an interface contract. If it's just
"why does this code change look this way", that's a [logbook](../../logbook/)
entry, not an ADR. When in doubt, log it; promote to an ADR only if it becomes a
load-bearing constraint others must design around.

## Format

- **Filename:** `NNNN-<kebab-case-title>.md`, zero-padded sequential (`0001-…`).
- **Frontmatter / heading** records `status` (`proposed | accepted | superseded`),
  date, and (if superseded) the superseding ADR.
- **Body:** Context → Decision → Consequences (and Alternatives considered).
- Add a row to the table below.

## Index

| ADR | Status | Title |
|-----|---|---|
| _none yet_ | | The first structural decision to arise will be recorded here. |

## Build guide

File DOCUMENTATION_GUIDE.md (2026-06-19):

# Documentation Guide

The single reference for **how documentation is organised in the Ball Butler
repo** — where each kind of information lives and how the layers cross-reference
each other. Consult it before creating or editing any markdown artifact.

Modelled on the [Jugglebot documentation system](https://github.com/Project-DeepBlue-Juggling/Jugglebot),
trimmed to what this (younger) repo actually uses. Layers Jugglebot has but
BallButler does not yet — a published MkDocs site, `plans/`, and a
`.claude/` automation layer — can be adopted from that repo when the need
arises; they are intentionally absent for now.

---

## 1. The cross-repo rule (read this first)

The Ball Butler V0 thrower's **ROS2 control stack lives in the
[Jugglebot](https://github.com/Project-DeepBlue-Juggling/Jugglebot) repo**, not
here. That includes `ball_butler_node`, `mocap_node`, `teensy_bridge_node`, and
the deployed aim-correction matrix under `ros_ws/.../resources/`.

**This repo (BallButler)** holds: firmware (`ball_butler_main/`), simulation
(`sim/`), test & analysis tooling (`zTesting/`), hardware design
(`ball_butler_circuit_diagram/`, `hand_sensor_pcb_rail/`), and the **engineering
record** (this guide, `logbook/`, `docs/adr/`).

Consequence: a single piece of work often spans both repos. The rule:

- **The narrative record lives in BallButler's `logbook/`** (this is where we
  document Ball Butler work), and it **cross-references Jugglebot by path**.
- Files changed *in this repo* go in a logbook entry's `files_changed:`.
- Files changed *in Jugglebot* go in `external_changes:` as
  `"Jugglebot: <path> (<what>)"`.

---

## 2. Documentation layers

| # | Layer | Path | What belongs here |
|---|---|---|---|
| 1 | **Public README** | [README.md](README.md) | Project identity: what Ball Butler is, V0 state, V1+ plan. Public-facing. |
| 2 | **This guide** | [DOCUMENTATION_GUIDE.md](DOCUMENTATION_GUIDE.md) | How docs are organised (you are here). |
| 3 | **Engineering logbook** | [logbook/](logbook/) | Per-change record: *why* a change looks the way it does, and whether it worked. |
| 3b | **Logbook chapters** | [logbook/chapters/](logbook/chapters/) | Narrative synthesis of a related block of entries (story + insights + open problems). Non-authoritative — links down to the entries. |
| 4 | **Architecture Decision Records** | [docs/adr/](docs/adr/) | Single significant, hard-to-reverse decisions. |
| 5 | **Inline source docs** | `*.cpp`, `*.py`, `*.h`, … | Docstrings / `why` comments next to the code. |

Duplication between layers is a bug. Keep authoritative content in one place and
cross-reference from the others.

> Claude's private memory (`~/.claude/.../memory/`) is **not** a documentation
> layer. Don't copy project docs there.

### 2.1 [README.md](README.md) — public landing

Project identity and the V0 → V1+ story. Keep it accurate to the hardware; it is
the first thing an outside reader sees. Not the place for investigation
write-ups.

### 2.2 [logbook/](logbook/) — engineering logbook

The authoritative record of every substantive change: symptoms/motivation,
diagnosis/design, the change, and the **measured** outcome. Full spec in
[logbook/README.md](logbook/README.md); copy [logbook/TEMPLATE.md](logbook/TEMPLATE.md)
to start one; [logbook/INDEX.md](logbook/INDEX.md) lists all entries.

Essentials:
- Filename `YYYY-MM-DD-<slug>.md` (3–6-word slug).
- Mandatory YAML frontmatter: `title`, `type`, `date`, `status`.
- `type` ∈ `investigation | bugfix | refactor | feature | optimization`; each
  type has its own body sections (see the logbook README).
- Maintained by hand — update [INDEX.md](logbook/INDEX.md) when you add or
  re-status an entry.

#### Chapters (`logbook/chapters/`) — narrative synthesis

A **chapter** reads a related block of entries top-to-bottom: the development,
the significant developments/insights, and the open problems — the high-level
picture the per-entry record and the flat [INDEX.md](logbook/INDEX.md) table
don't give. Self-contained HTML (sidebar nav, plots, links), browsable offline.

A chapter is a **reading lens, not a source of record.** It must not introduce
authoritative facts; every headline number links down to the entry that owns it
(this keeps "duplication is a bug" intact). Write one when a block of work
reaches a natural close; update it when a related entry lands or an open problem
resolves. List it in the **Chapters** table at the top of `INDEX.md`. (This is
the local, no-build precursor to the MkDocs site noted below; if that lands,
chapters become Markdown pages.)

### 2.3 [docs/adr/](docs/adr/) — Architecture Decision Records

One file per significant, costly-to-reverse decision (a frame convention, a
hardware split, an interface contract). The logbook records *what happened*; an
ADR records *why a structural choice was made* and what was rejected. Format and
the running index live in [docs/adr/index.md](docs/adr/index.md). If a decision
is really just "why this code change looks this way", it's a logbook entry, not
an ADR.

### 2.4 Inline source documentation

- **File/module header** — one line when the filename doesn't make the role
  obvious.
- **Comments document *why*, not *what*** — a hidden constraint, a sign/unit
  convention, a workaround for a specific bug. If deleting the comment wouldn't
  confuse a future reader, don't write it.
- **No task-journal comments** ("added for the X run") — that belongs in the
  commit message and the logbook.
- **Control/geometry conventions inline are load-bearing.** Sign conventions,
  frame definitions, and unit conventions in comments are normative — update them
  in the same change as the code.

---

## 3. Decision tree — "I need to document X"

- **The *why* behind a concrete change, and whether it worked?**
  → Logbook entry. Cross-reference Jugglebot paths under `external_changes:` if
  the control stack was touched.
- **A high-level narrative tying a block of entries together?**
  → Logbook chapter in [logbook/chapters/](logbook/chapters/). Synthesis only —
  link down to the entries; don't restate them as new authority.
- **A significant, hard-to-reverse structural decision?**
  → ADR under [docs/adr/](docs/adr/).
- **The *why* behind a single line/block of code?**
  → Inline comment, only if non-obvious. Otherwise the logbook is the better home.
- **Public project description?**
  → [README.md](README.md). Keep it minimal and accurate.
- **None of the above fit.** → Ask before inventing a new layer.

---

## 4. Maintenance

Keep this guide current when a layer is added or its conventions change. If this
repo later adopts Jugglebot's `plans/`, MkDocs site, or `.claude/` automation,
add the corresponding layer here and in the table above.

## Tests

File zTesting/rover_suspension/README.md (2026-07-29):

# Rover suspension design tool

Interactive design-space explorer for the BB rover's parallel-bar (parallelogram)
suspension: two bars of length `L` link the chassis wall to the vertical wheel
plate, with a spring-damper pinned between the bars at along-bar distances `x1`
(upper) and `x2` (lower); wall pivots are `h` apart vertically.

**Open `suspension_tool.html` in any browser** (no server, no dependencies):

```
xdg-open zTesting/rover_suspension/suspension_tool.html
```

Sliders for geometry / load / travel drive an animated side view, stat tiles, and
four charts (spring length, motion ratio, spring force at 1g + a dynamic G-factor,
and pivot loads incl. bar axial + bending at the spring pins). Every chart has a
hover tooltip and a table view. Parameters persist in localStorage; "Reset
defaults" clears them.

## Model (sign conventions)

- θ = bar angle above horizontal; active height `z = L·sinθ`; θ > 0 = compression.
- `d = x2 − x1`. Spring length `s(θ) = sqrt(d² + h² − 2·h·d·sinθ)`.
- Motion ratio `ds/dz = −h·d/(L·s)` (cosθ cancels exactly).
- Spring force (virtual work): `F = N·L·s/(h·d)`, `N` = quarter-vehicle weight × G.
  `d > 0` loads the unit in compression, `d < 0` in tension.
- Pivot loads: 9-equation rigid-body statics (two bars + plate, massless links,
  vertical wheel load at horizontal offset `w` from the plate). `w` affects pivot
  loads only, never the spring force.

Note an earlier hand derivation `s = sqrt((x2−x1)² + (h/cosθ)²)` is **wrong**
(2026-07-28, confirmed by two independent blind derivations): it is symmetric in
±θ and predicts spring stroke even when `x1 = x2`, where the true length is
constant `h`.

## Verification chain

1. `verify_statics.py` (`/usr/bin/python3`, 3.8-compatible): 2000 randomized
   configurations — the 9×9 statics solve matches the virtual-work spring force
   to <1e-13 relative, spring force is independent of wheel offset, and global
   force/moment equilibrium holds. Prints fixed-case reference numbers.
2. The JS physics block in the HTML was extraction-tested in node against those
   reference numbers (26 checks).
3. The page re-runs a fixed regression case + a sweep self-check on every load —
   see the "Physics self-check" badge in the footer.

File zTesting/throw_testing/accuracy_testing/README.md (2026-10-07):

# Accuracy calibration

## Local two-ball campaign (2026-10)

Use [LOCAL_CALIBRATION.md](LOCAL_CALIBRATION.md) and
`run_local_calibration.py` for the randomized 50–200 mm nonuniform grid,
corrected hand geometry, and automatic raw ROS2/MCAP capture. This is the
current diagnostic routine for the mirrored-hand investigation. It does not
change or reuse the old affine. The legacy flow below remains for historical
sessions and QTM-export fitting.

## Current flow (2026-05 onward)

The host-side aiming code lives in Jugglebot's `ball_butler_node.py`, which
owns the Cartesian-target → joint-space IK. To re-fit the affine correction:

1. **Run the session.** With the Jugglebot stack running, call the service:
   ```
   ros2 service call /bb/start_accuracy_calibration std_srvs/srv/Trigger
   ```
   `ball_butler_node` fires 50 throws (5×5 grid × 2 each, randomised order,
   fixed seed logged in the metadata JSON). It writes a metadata JSON to
   `~/bb_calibration_sessions/accuracy_session_<timestamp>.json` containing
   the exact throw schedule, grid params, BB pose, and whether any existing
   affine was applied. The rosbag captures every `ThrowAnnouncement`.

   To cancel mid-session:
   ```
   ros2 service call /bb/cancel_accuracy_calibration std_srvs/srv/Trigger
   ```

2. **Record QTM** in parallel and export ball trajectories to a `.json` file.

3. **Fit the affine.** From this directory:
   ```
   python fit_affine.py \
     ~/bb_calibration_sessions/accuracy_session_<timestamp>.json \
     ~/Desktop/qtm_export.json \
     --out throw_affine_correction.json
   ```
   The script pairs each ball trajectory to its commanded target by throw
   order (no manual cluster-mapping needed), transforms both into BB-local
   frame using the BB pose recorded in the session metadata, fits the 2D
   affine in BB-local frame, and writes `throw_affine_correction.json` plus
   a `.png` visualisation.

4. **Apply.** Copy `throw_affine_correction.json` into
   `Jugglebot/ros_ws/src/jugglebot/resources/` (the location
   `ball_butler_node` searches by default), then launch with the correction
   enabled:
   ```
   ros2 launch jugglebot jugglebot_launch.py \
     apply_aim_correction:=true
   ```
   Or override the file path via the `aim_correction_file` ROS param. The
   node logs whether it loaded a correction on startup.

5. **Verify.** Re-run the calibration session with the correction loaded;
   mean error should drop substantially. Launch with
   `apply_aim_correction:=false` to disable without removing the file.

## Historical sessions (older workflow)

Sessions 1-8 below used the now-archived `ball_butler_volley_testing_node`
and the manual cluster-mapping pipeline in `volley_viz.py`. The new flow
above replaces both.

- session 1 and 2 - 10 throws to 8 x 8 grid of 800 x 800 mm. Session 1 is first 368 throws, session 2 is rest (note that some throws were skipped due to them being unreachable)
- session 3 and 4 - 5 throws to 2 x 2 grid of 200 x 200 mm. Both had correction transformation matrix (from session 1 and 2) applied
- session 5 - 4 throws to 5 x 5 grid of 1000 x 1000 mm. No correction transformation matrix applied (post QTM calibration, and post fixing rotation bug from `global_to_bb_frame`
- session 6 - same as session 5, but after correcting the forward kinematics (with s, d and l offsets)
- session 7 - Timing test. 5 throws to each of 4 'delays'. Min delay = 2.0 sec, max delay = 5.0 sec, with 4 divisions. All aimed at (0, 0, 750) mm
- session 8 - same as 7, but after major refactor. Might fix throw delay?

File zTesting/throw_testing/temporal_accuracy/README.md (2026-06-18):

# Temporal accuracy — test protocol (v1)

Validates Ball Butler's **temporal** accuracy: does the ball arrive when the
system says it will? The spatial campaign (../accuracy_testing/) validated
*where* balls land; this protocol validates *when*, using the sensorized
catching cone as a mocap-free, microsecond-grade arrival sensor.

## Measurand

**End-to-end arrival error** per throw:

```
arrival_error = t_catch − t_landing_predicted
```

- `t_landing_predicted` — `landing_time` from the `ThrowAnnouncement`
  published by `ball_butler_node` at command time
  (= now + throw_delay_s + predicted ToF from the inverse-ballistics solver).
- `t_catch` — wall-clock instant the ball strikes the bottom of the catching
  cone, latched in the cone Teensy's piezo ISR with its clock IIR-locked to
  the system-wide 0x7DD time-sync broadcast (µs-level within the Teensy
  domain; the can-bridge anchors that domain to the Jetson's CLOCK_REALTIME).

This is deliberately end-to-end: it integrates every contributor — ROS →
UDP → CAN command latency, firmware wall-clock scheduling, release lag,
ToF-model error, and the cone-entry → piezo fall-through time. Decomposing
release error vs flight error requires QTM alongside
(../accuracy_testing/timing_analysis.py) and is out of scope for v1.

### The systematic offset δ

The protocol treats the total systematic as **δ**, estimated as the mean
arrival error of the repeatability block and subtracted before judging
accuracy. δ's *stability* across delays and distances is itself a result.

Measured composition (2026-06-10 campaign, δ = +126.5 ms — full analysis in
`logbook/2026-06-10-temporal-accuracy-protocol.md` + `decompose_results.json`):
**+82 ms** release lag (firmware decel-zero defect: ball leaves at
throw_time + 0.273/v), **+51 ms** flight stretch (ball releases ~10% hot in
vz), **−7 ms** ball-radius-early piezo contact. Geometry contributes almost
nothing — the cup surface sits at the rigid-body-origin plane, and drag is
<1 ms. Both dominant terms are thrower-side and speed-dependent (expect δ to
drift across a distance sweep), and both are fixable — but fixing them moves
the release point/velocity and **invalidates the deployed spatial
aim-correction** (re-fit required).

## Measurement chain (must be live before any session)

```
piezo ISR → cone Teensy (CAN2, CATCH_EVENT 0x7E0, wall-µs latched at impact)
          → can-bridge Teensy (CONE_FRAME UDP relay, ≤10 ms forwarding)
          → teensy_bridge_node → ROS topics cone/catch_event + cone/heartbeat
```

Forwarding latency does **not** enter the measurement — the timestamp is
latched at the ISR; only the cone's time-sync quality matters. Command
granularity is ~1 ms (16-bit epoch-ms CAN encoding of the throw time), so the
cone out-resolves the thing being measured by ~3 orders of magnitude.

## Preflight (gates; the runner enforces these)

1. Jugglebot stack up: `teensy_bridge_node`, `ball_butler_node`, `mocap_node`
   with the `Catching_Cone` rigid body tracked (mocap is used to *aim*, not
   to measure).
2. `cone/heartbeat`: `connected`, state READY, `time_synced=true`,
   `sync_rms_us ≤ 50` (warn above).
3. `bb/heartbeat`: `connected`, `ball_in_hand=true`, hopper loaded.
4. **Tap test**: `python3 run_temporal_session.py --listen`, tap the cone
   bottom — a catch event must print with a timestamp within ~1 s of "now"
   (the ~30 ms report deferral + UDP hop are normal), sequence incrementing
   per tap, and retriggers within 500 ms suppressed.

## Phases

Run R first (it calibrates δ), then D, then X. One ball type throughout;
record any hardware change in the session label.

| Phase | Purpose | Procedure |
|---|---|---|
| **R — Repeatability** | Throw-to-throw timing scatter; calibrates δ | N≥30 identical throws, nominal config (`--phase repeatability --throws 30 --delay 2.5`) |
| **D — Delay sweep** | Wall-clock scheduling vs lead time | Fixed cone; delays 2.0–5.0 s, ≥6 throws each, randomized order (`--phase delay-sweep --delays 2.0 2.75 3.5 4.25 5.0 --throws-per 6`) |
| **X — Distance sweep** | Constant vs ToF-proportional error | ONE interactive run: 5 throws to the current cone position, then the runner pauses (press Enter) while you move the cone — vary distance **and height** — repeating for 20 positions (`--phase distance-sweep --positions 20 --throws 5 --delay 2.5`). Gates are re-checked after every move; a failed throw (e.g. QTM lost the moved body) offers retry instead of aborting. q at any prompt ends the session early, keeping all data. |

Throws auto-pace on BB's reload cycle (same heartbeat gating as the spatial
calibration session). A session aborts cleanly if the hopper runs dry; data
written so far is preserved (JSON is rewritten after every throw).

## Data handling

- Sessions land in `sessions/temporal_<phase>[_<label>]_<stamp>.json` —
  per-throw records: commanded delay, full service response (yaw/pitch/
  speed/ToF/targets), the announcement's `throw_time`/`landing_time`, the
  catch event (timestamp, sequence, flags), and `arrival_error_ms`.
  Distance-sweep throws additionally carry `position`/`position_idx`
  (`pos01`…); the analyzer groups per position automatically.
- **Exclusions are recorded, never silently dropped**: `miss` (no catch
  within ±1.5 s of predicted landing — ball missed the cone or sensor failed
  to trigger), `unsynced` (cone lost time-sync — timestamp is host-arrival,
  not impact truth), `throw-failed`. A phase with >20 % misses is invalid —
  fix aim (re-run spatial validation) or cone placement first.
- Rim-graze ambiguity: a wall hit can trigger the piezo early. The
  `retrigger_suppressed` flag marks extra edges in the 30 ms report window;
  treat flagged throws as suspect when they are outliers.
- Resolved anomaly (2026-06-10 bench, 1/18 taps): a cone-firmware ISR race
  (`micros64()` false 32-bit wrap) could put a future-biased timestamp on a
  catch sent within ~1 s of a wrap — root-caused and fixed the same day, see
  Jugglebot `logbook/2026-06-10-cone-micros64-false-wrap.md`. The ±1.5 s
  match window still rejects any recurrence (shows as a `miss` with a catch
  event present); a miss rate dominated by that signature means the cone
  firmware regressed.

## Analysis & pass criteria

```
/usr/bin/python3 analyze_temporal_session.py sessions/temporal_delay-sweep_*.json \
    --offset-from sessions/temporal_repeatability_<stamp>.json --plot
```

With δ from phase R removed, the system **passes** when every group (each
delay bin in D, each position in X, and R itself) shows

```
|mean(arrival_error) − δ| ≤ 10 ms
```

Also report (characterization, no gate in v1): scatter σ per group, the
trend slopes vs commanded delay (scheduling-chain health — should be ~0)
and vs predicted ToF (flight-model health), and the miss/unsynced counts.

Note for the 20×5 distance sweep: at n=5 per position each group mean
carries ~±4 ms standard error (σ ≈ 9 ms from phase R), so treat individual
per-position verdicts as advisory — the primary phase-X signal is the trend
vs predicted ToF (plus the per-group v/ToF context the analyzer prints)
across all ~100 throws.

## Next step (out of scope for v1): timing correction

If a stable bias structure emerges (e.g. δ component scaling with ToF), fit
a correction mirroring the spatial affine flow: estimate offset(+slope vs
ToF) from one campaign, apply it to `predicted_tof_sec`/`landing_time` in
`ball_butler_node` (analogous to `_apply_aim_correction`), then validate on
a fresh campaign against the same ±10 ms criterion. Decomposition into
release vs flight error (QTM + `timing_analysis.py` alongside a cone
session) is the follow-up if the residual resists a simple model.

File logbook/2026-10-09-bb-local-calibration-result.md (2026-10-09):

---
title: Full local calibration after BB reinstall — candidate affine for positive s
type: investigation
date: 2026-10-09
status: tuned
related_entries:
  - 2026-10-07-pilot-trajectory-extraction-fix
  - 2026-10-06-local-calibration-analysis
  - 2026-10-05-mirrored-hand-local-calibration
files_changed:
  - logbook/2026-10-09-bb-local-calibration-result.md
  - logbook/INDEX.md
  - zTesting/throw_testing/accuracy_testing/run_local_calibration.py
  - zTesting/throw_testing/accuracy_testing/analyze_local_calibration.py
  - zTesting/throw_testing/accuracy_testing/test_local_calibration.py
  - zTesting/throw_testing/accuracy_testing/test_analysis_local_calibration.py
  - zTesting/throw_testing/accuracy_testing/LOCAL_CALIBRATION.md
  - zTesting/throw_testing/accuracy_testing/local_validation_plan.json
  - zTesting/throw_testing/accuracy_testing/local_validation_plan.html
external_changes:
  # The production change lives in the Jugglebot repo, branch bb-positive-s-affine-2026-10-09
  # (Jugglebot logbook/2026-10-09-bb-positive-s-and-refitted-aim-correction.md and
  # logbook/2026-10-09-bb-yaw-root-fix.md).
  - "Jugglebot: config/hardware_config.yaml + regenerated artifacts (ball_butler_geometry.yaw_s_offset_mm -105.65 -> +105.65)"
  - "Jugglebot: ros_ws/src/jugglebot/resources/throw_affine_correction.json (the 2026-10-09 refit, validated; the 2026-06-09 matrix archived as throw_affine_correction_2026-06-09_negative_s.json)"
  - "Jugglebot: ros_ws/src/jugglebot/jugglebot/ball_butler_node.py (refuses a matrix fitted for the other sign of s)"
  - "Jugglebot: ros_ws/src/jugglebot/jugglebot/can/throw_ballistics.py + sim/ball_butler/sim.py (yaw solve always takes the positive-range root)"
  - "Jugglebot: sim/juggle_catch.py + sim/juggle_bb_catch.py (the BB-feed sims throw from the measured 2026-10-09 placement)"
  - "Jugglebot: config/generated/admissible_box.yaml (re-swept: hardware_config.py is a gated file)"
subsystem:
  - calibration
  - throwing
tags:
  - accuracy
  - ballistics
  - mocap
---

# Full local calibration after BB reinstall — candidate affine for positive s

## Symptoms

Before this run, BB had to be removed from its shelf, modified and reinstalled. **Only**
session `~/bb_calibration_sessions/20261009T002142_931068Z` is valid for calibration. Every
earlier session, including the 2026-10-07 pilots and the 2026-10-08 partial runs, predates the
reinstall and must not be pooled with it.

## Diagnosis

### Capture

The session is a single, standalone run.

**Setup**
- Status `completed`; no `--resume-from`.
- Solver: `Jugglebot-skills` `throw_ballistics.py` (sha256 `bbb80fa5…`).
- `s = +105.65 mm`; the affine and the feed bias were bypassed.
- Frame translation: `schedule_to_mocap = (0.3, −0.6)`.
- Post-reinstall BB pose: (−975.6, −389.3, 1734.9) mm, yaw offset 0.208°. That is ~1 mm and 0.36° from the 2026-10-07 pose.

**Throws**
- 277/277 released, all on the first attempt: no yaw-NOT_SETTLED retries, no abandoned entries, no rejected captures.
- Duration 57 min with 31 refills. Largest QTM source-stamp gap 38 ms; `recording_needs_review: false`.

**Extraction:** 275/277 accepted.
- The two rejections (throw 74 / cell 90 and throw 77 / cell 116) are `catch_coverage`: the ball was unseen for the last 32–67 ms before the crossing. Both are legitimate.
- Accepted fits:

| metric | range |
|---|---|
| fit RMS | 0.4–3.8 mm |
| local crossing RMS | ≤1.5 mm |
| launch closest approach | ≤22.7 mm |
| acceleration error | ≤428 mm/s² (gate 588) |
| apex occlusion gap | up to 0.417 s (gate 0.45, the closest margin) |

### Results (BB-local frame, 116 cells)

| quantity | value |
|---|---|
| uncorrected per-throw error | mean (+44.3, +9.2) mm, RMS 54.4 mm (core: 47.9 mm, mean (+42.0, +9.8)) |
| forward affine | [[1.0751, 0.0253, −40.80], [0.0186, 1.0153, −16.56]]: gains 1.082 / 1.008, rotation −0.18° |
| correction (desired → command) | [[0.93058, −0.02322, 37.582], [−0.01706, 0.98531, 15.622]] |
| drift over 57 min | quarter means within ±5 mm; linear (−0.2, +3.4) mm. None |
| per-throw scatter (repeats) | σ ≈ 16.2 / 9.8 mm (x / y); 16.5 radial, 9.3 lateral; 2D 19.0 mm (core 20.7) |
| cell-mean noise floor | 13.0 mm RMS |
| held-out cell residual | affine 17.4–17.7; quadratic 17.3; cubic 17.4; mean-offset only 29.5 mm |
| predicted corrected per-throw error (held-out cells) | grid RMS 21.8, median 17.0, p95 38.6 mm; core RMS 21.3 mm |

## Discussion

**What the data shows**
- **The systematic error is affine.** It is stable over the hour, and higher-order models do no better on held-out cells.
- **In the core, the correction should reach the repeatability floor.** The predicted 21.3 mm per throw is close to the 20.7 mm scatter.
- **Some residual remains unexplained.** About 10 mm grid-wide, mostly radial, fits no smooth model. It is either cell-specific or heavier-tailed throw noise. It is small next to the scatter.
- **Repeatability is now the limit, not aim.** The scatter is mostly radial, which points to speed or release variation.

**Not trusted: launch-state comparisons**
- Measured against predicted release velocity reads +10 % speed, +3° elevation, −3.6° azimuth. That is the shape of the earlier "hot launch" artifact.
- It comes from evaluating the arc 49 ms earlier, where v_z is ~480 mm/s higher.
- The azimuth comes from the ~134 mm/s² lateral acceleration. The measured launch direction differs from its own release-to-landing chord by −3.2°, while the landing bearing error is −0.25°.
- Only landings are used.

**Persists after the reinstall:** the arc passes the predicted release point 49 ms early (median; range −69 to −21 ms). The affine absorbs this; the root cause is still open.

## Fix

Candidate: `20261009T002142_931068Z/analysis/correction_candidate.json`. It requires positive s
and replaces the 2026-06-09 affine (do not stack them). Valid for BB-local x 386–1570 mm,
y 195–928 mm, catch z 830 mm, and this mounting of BB only.

The production change (s sign + affine) is prepared separately. It is **not deployed**
until a corrected hardware validation run passes; see Outcome.

### Validation set-up (agreed 2026-10-09; criteria fixed before the run)

- **Runner:** `--apply-correction` maps each desired BB-local target through the candidate and solves the command with s = +105.65.
  - `target_*` stays the desired point; `command_bb_local_mm` records the solved point.
  - Targets outside the fitted region are skipped.
  - The runner refuses a candidate whose s, frame or solver sha differs.
- **Plan:** `local_validation_plan.json` (sha256 `039355da…`, seed 1042).
  - The core is shifted +25/+25 mm, half a grid step, so every target is a position the fit never saw.
  - Each cell is thrown once and the core twice.
  - Offline, against the installed solver and the 2026-10-09 pose: 110 feasible throws over 95 cells, 30 in the core, about 27 min.
  - This replaces "the first 80 throws of a seed-1042 plan" agreed earlier. That would give only 11 core throws, barely above the 10-throw minimum, and would reuse fitted positions.
- **Criteria** (`VALIDATION_CRITERIA`, errors in BB-local mm, measured minus desired):
  - mean within ±6 mm per axis;
  - per-throw RMS ≤26 mm overall and ≤25 mm in the core (predicted 21.8 / 21.3);
  - a verdict needs ≥60 accepted throws, ≥10 core throws and ≥90 % of releases accepted, otherwise INCONCLUSIVE;
  - only PASS justifies deployment.
- **Analysis:** corrected sessions are analysable only with `--extract-only`, so they can never be fitted as uncorrected.

## Outcome

### Validation run (session `20261009T031319_612936Z`, 2026-10-09)

110/110 corrected throws released and accepted (95 cells, 30 core throws, no retries, no
rejections). Errors in BB-local mm, measured minus desired:

| quantity | value | criterion |
|---|---|---|
| mean | (+1.6, −8.2) | within ±6 per axis — **fails on y** |
| per-throw RMS, grid | 21.0 | ≤26 (predicted 21.8) — passes |
| per-throw RMS, core | 20.9 | ≤25 (predicted 21.3) — passes |
| repeat-cell scatter (15 cells) | 14.1 | — |

The verdict against the pre-registered criteria is **FAIL**, on the lateral mean only. The
correction did what the fit predicted: 54 → 21 mm per throw, which is the repeatability floor.

**Where the lateral mean comes from (instrument first).** The two sessions' BB pose
calibrations differ:

| pose field | calibration session | validation session |
|---|---|---|
| position (mm) | (−975.6, −389.3, 1734.9) | (−976.5, −390.6, 1734.3) |
| yaw offset | 0.208° (σ 0.07°) | 0.681° (σ 0.04°) |
| axis tilt | 0.76° | 1.15° |

A +0.47° rotation of the BB-local frame moves a landing at the 0.97 m mean range by −8.0 mm
in local y: the sign and size of the failing mean. Re-expressed in the calibration session's
frame the mean is (−2.9, −1.6) mm and the RMS 19.4 mm. The per-throw regression of y error on
range cannot separate rotation from translation (intercept −5.5 ± 3.9 mm, slope −0.16 ± 0.22°),
so this is consistent with, not proof of, a frame effect; the direct evidence is the pose
calibration itself moving by 0.47° while its own quoted σ is 0.04–0.07°. The yaw offset is the
angle of one anchor marker about the fitted axis point, so an axis-point difference of 1.7 mm
(as seen here) shifts it by 1.7 mm / r: 0.5° if the anchor sits r ≈ 200 mm from the axis. A second-order hint: the radial error has a
slope of −17 ± 7 mm per metre of range, i.e. the fitted 1.082 gain reads ~1.065 in this
session.

**Decision (owner, 2026-10-09): accept the candidate and deploy.** The failing criterion is
an 8 mm lateral mean of the size the pose calibration itself moves between sessions, which no
affine fitted in one session can remove; the RMS criteria pass at the predicted floor. This is
a documented deviation from the pre-registered PASS requirement, not a re-interpretation of
the criteria: the mean check was written to catch a wrong translation column, and the data say
the translation is right in the frame it was fitted in.

**Follow-ups, outside this entry's scope:**
- Per-session yaw-offset repeatability of the BB pose calibration (0.47° here ≈ 8 mm at 1 m).
  Check the anchor-marker radius and the axis-fit residuals across the two sessions' arcs.
- The ~48 ms arc-time offset (unchanged).

### Production change

Prepared and gated in the Jugglebot repo (`external_changes` above): s = +105.65, the matrix
installed with its validation recorded in the resource provenance, the box re-swept, the
BB-feed sims moved to the measured placement, and the yaw-root fix. Deployment steps
(merge, build, check the node's `Aim correction source` line, a handful of throws) are in the
Jugglebot entry.

**Solver sha after the yaw-root fix.** The runner's `--expect-solver-sha bbb80fa5` refers to
the solver before the fix. The fix changes no command inside the calibrated region (every
target there takes the forward root), so `run_local_calibration.py` now judges a solver file
whose sha differs from the candidate's by re-solving the fit session's recorded throws and
demanding identical solutions, instead of refusing on the sha alone.

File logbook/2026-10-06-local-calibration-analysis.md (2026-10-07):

---
date: 2026-10-06
status: tuned
type: feature
subsystem: calibration, tooling
---

# Refill-aware trajectory extraction and simulated calibration validation

The capture runner already marked successful BB flight windows and refill
intervals, but did not yet extract noisy trajectories or fit a replacement
correction. The owner requested analysis ready immediately after the sitting,
tested with +/-2 mm readings, 1% throw-state errors and ground bounces.
Jugglebot will remain connected; no disconnected-platform mode is needed.

Added `analyze_local_calibration.py`, accepting the recorded session plus raw
ROS2 MCAP, or identically structured synthetic observation frames. It excludes
refill/failed/incomplete windows, seeds gravity-constrained RANSAC near BB's
release state, measures the descending catch crossing and rejects ambiguous
or insufficient tracks. There is no target-XY proximity selection. The affine
is fitted commanded-to-measured with equal weight per cell, then inverted in
BB-local coordinates. Whole-cell cross-validation and core-area/repeatability
metrics are reported. Output remains a candidate: production geometry and
the historical affine have not been changed.

`simulate_local_calibration.py` generates all331 throws at200Hz with shuffled
unlabelled markers, static clutter, refill projectiles every9 throws, small
bounces/rolling and disappearance one second after impact. The systematic
mocap XY response is [[1.012,0.008,10],[-0.006,0.990,20]]. Independent uniform
+/-1% velocity-component errors are applied per throw; release position is
unchanged. Every observed coordinate has independent uniform +/-2mm noise.
A synthetic BB pose makes all planned targets reachable. The analysis never
reads truth.json.

## Outcome and verification

All331 simulated throws extracted across143 cells, none rejected. Extraction
error against hidden truth:0.237mm RMS. Recovered command correction vs true
inverse:1.004mm RMS. An independent validator re-solves corrected commands and
tests2860 fresh throws (300 core), each before/after with paired fresh random
state errors. Full-grid RMS:25.33→10.57mm. Core RMS:24.36→10.10mm; mean core bias
(+10.03,+19.70)→(-0.45,-0.26)mm. Remaining scatter is largely injected random
state variation, which an affine cannot cancel.

23 tests pass, including noise/clutter/bounce extraction, competing trajectory
rejection, absent/occluded balls, affine direction/rank and an actual ROS2 MCAP
encode/decode test. Scripts parse as Python3.8. Raw simulation remains outside
the repository; compact results and deterministic regeneration scripts are
committed. See [usage and results](../zTesting/throw_testing/accuracy_testing/LOCAL_CALIBRATION.md).

No hardware was commanded. Real QTM/DDS timing, visibility and corrected-throw
accuracy still require the hardware pilot. The fitted candidate requires the
positive-s geometry and replaces, rather than compounds, the old affine.

## First hardware pilot: UUID serialization fix (2026-10-07)

The first action was dispatched and accepted, then checkpointing failed with
`Object of type uint8 is not JSON serializable`. ROS2 exposes the goal UUID
as a NumPy uint8 array; converting it with `list()` preserved NumPy scalars.
The same invalid row also broke the final checkpoint. Convert each UUID byte
explicitly to a Python int before storing it. A regression test uses an actual
NumPy uint8 array and checks accepted/event/failure JSON persistence.
The interrupted session must not be resumed or treated as a confirmed failed
throw: its first command may have executed. Start a fresh pilot after updating.

The next ten-throw pilot completed all captures. Finalized metadata contained
27,234 mocap messages, 35 events and the calibration record; no validation or
close error was present. Recorder exit code 2 after requested SIGINT alone
caused the review flag. Accept this Foxy shutdown case only when we requested
SIGINT, metadata validates and no close timeout occurred. Other nonzero exits
remain flagged. Destroy the action client before its node to avoid the Foxy
destructor InvalidHandle traceback. Added `--extract-only` for the ten-throw
pilot, which intentionally cannot satisfy the full affine's 12-cell minimum.
25 tests pass, including shutdown classification; extraction-only recovers
all ten synthetic pilot flights. Hardware bag extraction is the next check.
Hardware bag extraction initially rejected all ten; see
[2026-10-07-pilot-trajectory-extraction-fix](2026-10-07-pilot-trajectory-extraction-fix.md).

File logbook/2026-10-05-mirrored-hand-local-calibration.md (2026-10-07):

---
title: "Mirrored-hand simulation and local two-ball calibration capture"
type: feature
date: 2026-10-05
status: tuned
subsystem: [calibration, tooling]
tags: [accuracy, mocap, ballistics, testing]
---

# Mirrored-hand simulation and local two-ball calibration capture

The user identified that BB's physical hand is left of the pitch plane when
throwing along +Y; the configured negative s puts it on the right. The offline
simulation explains most of the archived uncorrected bias: 211.3 mm predicted
versus 194.6 mm measured mean miss, 42.3 mm mean prediction discrepancy, and
9.2 degrees mean directional difference. It does not explain the whole
affine-corrected residual. Full evidence is in
[the experiment report](../zTesting/throw_testing/accuracy_testing/mirrored_hand_report.md).

Added an offline nonuniform-grid planner and ROS2 session runner in
`zTesting/throw_testing/accuracy_testing/run_local_calibration.py`. The runner
uses production ballistics with explicit positive s and no affine, awaits the
existing `/bb/throw` terminal result, captures raw MCAP and per-goal provenance,
and keeps uncertain/failed throws explicit. Normal Jugglebot configuration is
unchanged. Grid defaults use the Oct 4 sitting-4 logbook's two-ball area;
original launch logs can refine it. Default: 143 targets / 331 throws before
reachability filtering, 50–200 mm spacing, 5 core / 2 outer repeats.

Fixed the comparison artifact's invalid Windows SVG encoding and clipped
bounds; regenerated an equal-scale PNG, inspected visually, plus UTF-8 SVG.
Usage and frame conventions: [local calibration guide](../zTesting/throw_testing/accuracy_testing/LOCAL_CALIBRATION.md).

Verification (2026-10-05): `python -m unittest discover -s
zTesting/throw_testing/accuracy_testing -p test_local_calibration.py -v`:
16 offline tests pass, including production ballistic round trips and nine-throw refill batching. No hardware
was commanded. Jetson DDS/action/MCAP integration and actual calibration
accuracy remain to be validated with a pilot session.

Before the hardware sitting, the owner clarified that balls are thrown back
into BB's magazine during calibration. The initial capture-only runner had
no explicit refill segmentation. Added operator-gated refill intervals (default
after every nine throws, as requested by the owner), continued ROS servicing during unlimited refill waits,
ground-arrival wait, per-throw analysis windows and a timestamp-association
helper that rejects refill/failed/incomplete/ambiguous intervals. Raw refill
arcs remain in the MCAP for audit; later extraction must use the windows and
not match every ballistic arc by order. The guide now explicitly requires
the normal ROS2 stack running; only its duplicate recorder can be disabled.

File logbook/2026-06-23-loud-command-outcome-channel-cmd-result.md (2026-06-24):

---
title: Loud command-outcome channel + bb/throw ROS2 action (CMD_RESULT) — Phase 2
type: feature
date: 2026-06-23
status: tuned   # Phase 2 hardware-validated 2026-06-24 (5/5 loud-throw-action tests on BB+can-bridge)
phase: V1 reliability
related_entries:
  - 2026-06-21-throw-settle-gates-loud-on-aim   # Phase 1 (A + C + serial); this is its Phase 2
files_changed:
  - ball_butler_main/BallButlerConfig.h          # CanIds::CMD_RESULT alias
  - ball_butler_main/CanInterface.h              # publishCmdResult() decl
  - ball_butler_main/CanInterface.cpp            # publishCmdResult() — 8-byte frame, heartbeat idiom
  - ball_butler_main/StateMachine.cpp            # emit at every throw terminal point (reject/abort/OK)
  - ball_butler_main/HandTrajectoryStreamer.h    # Layer-C abort emits ABORTED_NOT_SETTLED + axis
  - ball_butler_main/protocol_config.h           # regenerated (CMD_RESULT id + command_types/outcomes)
  - zTesting/throw_testing/validate_loud_throw_action.py   # Phase-2 validation driver (asserts firmware outcomes via the action)
external_changes:
  - "Jugglebot: config/protocol_config.yaml (ball_butler.CMD_RESULT=0x7D5 + command_types/command_outcomes enums)"
  - "Jugglebot: config/generate_config.py (emit the two enums C++/Py; add Teensy_code_canbridge to extra_copies — was stale, a build blocker)"
  - "Jugglebot: config/generate_udp_protocol.py (uplink MsgType.CMD_RESULT=0x87 + CmdResultFrame raw-CAN relay struct)"
  - "Jugglebot: config/generated/* + copies (protocol_config.h/.py, udp_protocol.h/.py regenerated into both repos)"
  - "Jugglebot: controller/teensy_link/{protocol.py,__init__.py} (re-export CmdResultFrame + CMD_RESULT_FRAME_SIZE)"
  - "Jugglebot: Teensy_code_canbridge/{can_buses.h,can_buses.cpp} (CmdResultFrameRec SPSC ring + on_bb_rx CMD_RESULT branch)"
  - "Jugglebot: Teensy_code_canbridge/{telemetry.h,telemetry.cpp,Teensy_code_canbridge.ino} (cmd_result_uplink_step relay from task_telem; [canhealth] drop counter)"
  - "Jugglebot: jugglebot_interfaces/action/BallButlerThrowCmd.action + CMakeLists.txt (new action type)"
  - "Jugglebot: jugglebot/teensy_bridge_node.py (bb/throw ActionServer, MultiThreadedExecutor + ReentrantCallbackGroup, CMD_RESULT sub + RX-thread completion; speed==0 aim/track fast-path; retired bb/send_throw_command)"
  - "Jugglebot: jugglebot/ball_butler_node.py (bb/throw ActionClient; fire-and-forget + async outcome logging)"
  - "Jugglebot: jugglebot/can_node.py (stale BB-services comment refreshed)"
  - "Jugglebot: tests/ros/{conftest.py,test_teensy_bridge_node_bb.py,test_ball_butler_node.py} + tests/teensy_link/test_protocol_codec.py (action infra mocks, service→action migration, CMD_RESULT loopback + round-trip)"
commits:
  - a6b9057   # BallButler: firmware emits + regenerated protocol_config.h + validation driver
  - 329a4b4   # Jugglebot (cross-repo): protocol + can-bridge relay + bb/throw action + tests
subsystem:
  - firmware
  - throwing
  - tooling
tags:
  - safety
  - throw
  - testing
---

# Loud command-outcome channel + bb/throw ROS2 action (CMD_RESULT) — Phase 2

## Summary

Phase 1 made BB throws *on-aim* (settle gates A + C) but the outcome was
**serial-only** — a firmware reject/abort never reached the host, and
`bb/send_throw_command` "success" only meant *frame queued at the bridge*. Phase
2 adds a **generic, reusable firmware→host outcome channel**: one `CMD_RESULT`
CAN message (0x7D5), relayed CAN1→UDP by the can-bridge, surfaced through a new
`bb/throw` ROS2 **action** whose result carries the firmware's terminal outcome
(OK / a `REJECTED_*` reason / `ABORTED_NOT_SETTLED`). The throw is the first
consumer; reload/calibrate/home can reuse the same mechanism. Code-complete; the
full Jugglebot suite is green (1746 passed, 1 xfailed). Hardware end-to-end
(flash BB + can-bridge, `ros2 action send_goal /bb/throw`) is the pending
operator step.

## Motivation

`StateMachine::requestThrow` rejects synchronously, but `executeThrow_` runs
later in `handleIdle_` *after* the RPC already acked — and the `BB_THROW` RPC
acks at the **can-bridge** (frame queued to CAN1), never at BB. So every
firmware-side reject/abort was invisible to ROS. Making throws "loud" needs a
BB→host frame the bridge explicitly relays, plus a host primitive that *awaits*
it — hence an action, not a service.

## Design

- **One generic `CMD_RESULT` frame** (8 bytes): `byte0=command_type`,
  `byte1=command_outcome`, `bytes2-3=detail0` (int16 LE), `bytes4-5=detail1`
  (int16 LE), `6-7` reserved. Not throw-specific.
- **Outcome encoding (decided at kickoff): outcome-as-extensions.** `command_outcomes`
  is a shared base enum (`OK/REJECTED/ABORTED/TIMEOUT/BUSY`, 0x00–0x0F) plus
  per-command extension values ≥0x20 carrying the *specific* reason
  (`THROW_REJECTED_NO_BALL`=0x20 … `THROW_ABORTED_NOT_SETTLED`=0x29). One field
  to switch on; the host derives category by range. `detail0/1` stay generic
  (for throws: detail0 = binding axis 0=YAW/1=PITCH/2=BOTH/-1=n/a, detail1 = a
  metric — lead shortfall ms / yaw error centideg). (Alternative considered:
  reason-in-detail0; rejected to keep the base enum the single switch surface.)
- **One outcome per throw, at the true terminal point.** Emitted at each
  `requestThrow`/`executeThrow_` reject, at the Layer-C abort, and — crucially —
  `OK` only at **completion** in `handleThrowing_` (not at arm), so an
  A-misprediction that aborts at C produces exactly one `CMD_RESULT`, never a
  premature OK.
- **No correlation token** — throws are serialized (one ball), so the host
  tracks a single outstanding goal per `cmd_type`.
- **Bridge relay mirrors the cone path** — a small SPSC ring filled in
  `on_bb_rx` (CMD_RESULT branch *before* the ODrive-decode fallthrough),
  drained by `cmd_result_uplink_step()` on `task_telem` → `udp_send_stream`.
- **Host: action + RX-thread completion.** `execute_callback` dispatches the
  RPC, then waits on a `threading.Event` (with `throw_time + 5 s` timeout) that
  the RX-thread `_on_cmd_result` sets. `goal_callback` rejects a second
  concurrent goal. The node moved to a `MultiThreadedExecutor` +
  `ReentrantCallbackGroup` so the result-wait never stalls the 100 Hz telemetry
  timers and a second goal can still be rejected promptly.
- **`bb/throw` is throw-OR-aim** (caught during bring-up). The retired service
  carried both throws (speed>0) and aim/track commands (speed=0 →
  `requestTracking`, which emits *no* `CMD_RESULT`). A speed=0 goal awaiting a
  result would hang until timeout (and the calibration-volley keepalive uses it),
  so the action treats speed=0 as a **fire-and-forget aim**: accepted without
  consuming the single-throw slot, dispatched, succeeded immediately. Only
  speed>0 enters the gate-and-await throw path.

## Implementation

Built in dependency order across ~5 components:

1. **Protocol** (`config/`): YAML id + two enum blocks; `generate_config.py`
   emits them (C++ namespaces + Python `IntEnum`) and — the **build-blocker
   fix** — adds `Teensy_code_canbridge/` to `extra_copies` (its
   `protocol_config.h` was hand-copied and stale, so it never had new ids).
   `generate_udp_protocol.py` adds the `CmdResultFrame` relay struct. Regenerated
   into both repos; `controller/teensy_link` re-exports `CmdResultFrame`.
2. **BB firmware**: `CanInterface::publishCmdResult()` (heartbeat frame idiom),
   wired at every throw terminal point; Layer-C abort emits from the streamer
   (it already owns the binding-axis decision).
3. **can-bridge**: `CmdResultFrameRec` ring + relay (verbatim mirror of the cone
   uplink), `cmd_result_fwd_drops` on the `[canhealth]` line.
4. **Host**: `BallButlerThrowCmd.action`; `teensy_bridge_node` action server;
   `ball_butler_node` swapped to an `ActionClient` (fire-and-forget send +
   async result-callback that logs the firmware outcome).
5. **Migration**: retired `bb/send_throw_command` (clean cutover); updated tests
   + conftest action mocks; added a `CMD_RESULT` loopback test and a codec
   round-trip.
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

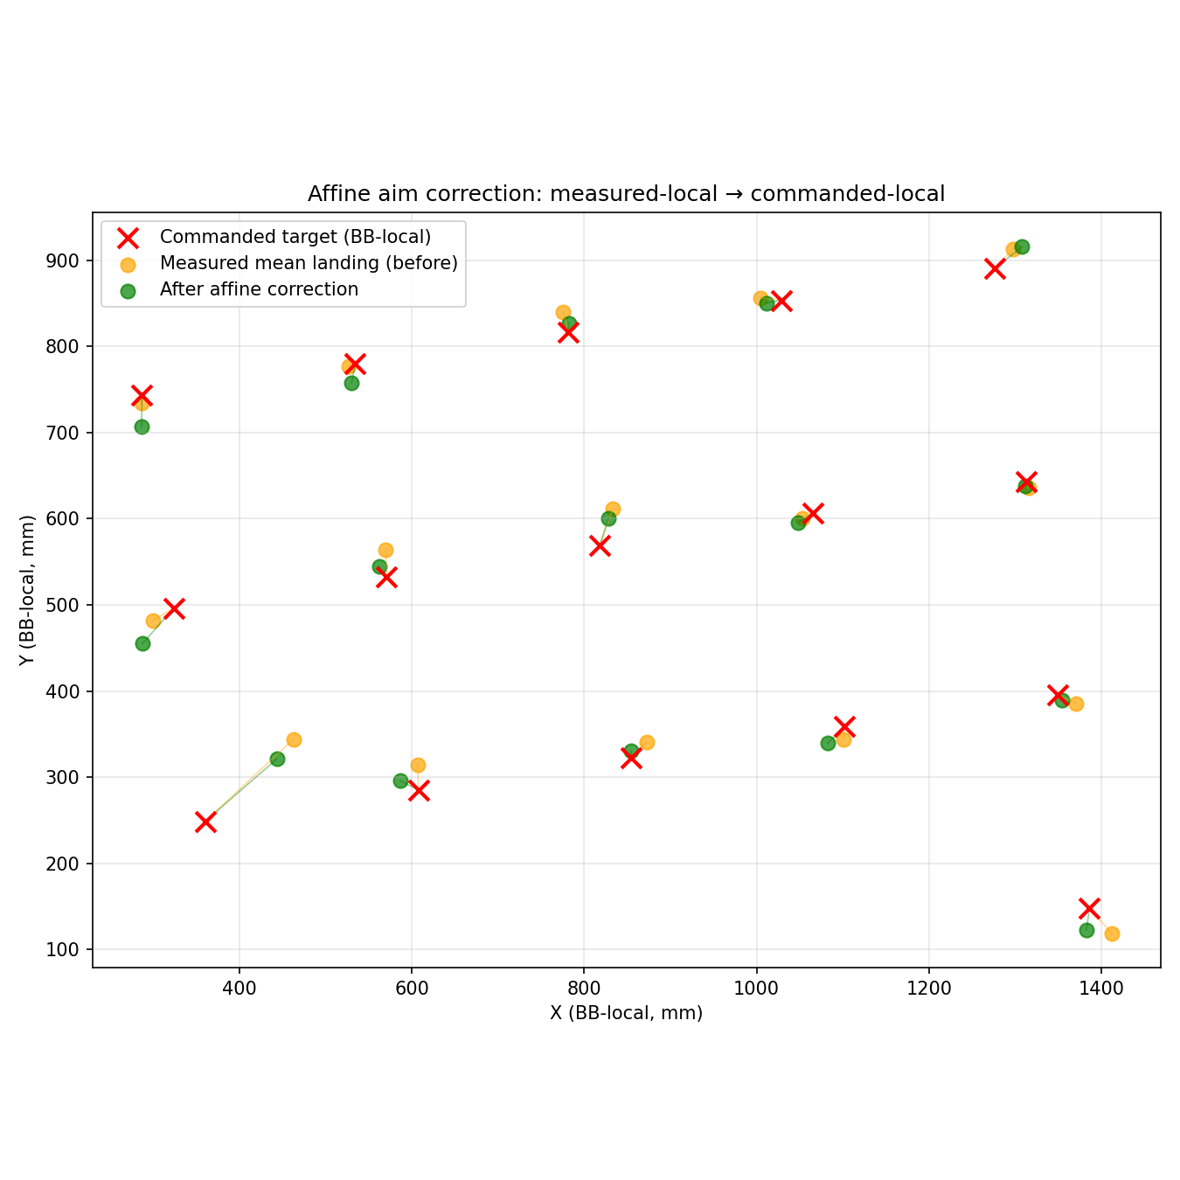
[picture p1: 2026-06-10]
zTesting/throw_testing/accuracy_testing/throw_affine_correction_v2_residual.png

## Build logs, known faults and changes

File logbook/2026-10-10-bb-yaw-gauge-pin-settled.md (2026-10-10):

---
title: BB yaw-offset gauge pin settled from landings — RE_PIN by −0.179° (0.208 → 0.029°) on the 23:34 range-weighted sitting; settle_yaw_gauge.py now evaluates the affine criteria itself when the report has no checks
type: investigation
date: 2026-10-10
status: resolved
phase: ""
related_adr: ""
related_entries:
  - 2026-10-09-yaw-gauge-settle-tooling
  - 2026-10-09-bb-local-calibration-result
  - 2026-10-10-bb-hand-torque-ff-scale
files_changed:
  - zTesting/throw_testing/accuracy_testing/settle_yaw_gauge.py
  - zTesting/throw_testing/accuracy_testing/test_settle_yaw_gauge.py
  - logbook/2026-10-10-bb-yaw-gauge-pin-settled.md
  - logbook/INDEX.md
external_changes:
  - "Jugglebot: ros_ws/src/jugglebot/resources/bb_marker_template.json (gauge.pinned_yaw_offset_deg 0.208 -> 0.029, gauge.repinned_on records the evidence; branch bb-yaw-gauge-repin-2026-10-10, not merged or deployed) + the two shipped-template tests and logbook 2026-10-09-bb-constellation-yaw-offset (\"Pin settled\")"
subsystem:
  - calibration
  - tooling
tags:
  - accuracy
  - mocap
---

# BB yaw-offset gauge pin settled from landings

## Summary

Two corrected sittings on 2026-10-10 after the hand-FF fix (FW 7 / FW 8) measured the constellation estimator's yaw-offset gauge against landings with `settle_yaw_gauge.py`. The 23:34 sitting (47 accepted) is the first to meet the pre-registered rule's ≥ 30 throws: mean bearing −0.179 ± 0.099°, outside ±0.15°, so **RE_PIN by −0.179°**: Jugglebot's `gauge.pinned_yaw_offset_deg` 0.208 → **0.029°**. The 19:23 sitting (28 accepted, below the rule) and the pool agree. While reading the 23:34 output, the script's affine line said "OUTSIDE criteria" for an RMS (24.6 mm) inside the 26 mm criterion. The report's validation was INCONCLUSIVE on counts and so had no `checks`. The script now evaluates the criteria itself.

## Symptoms

- 23:34 output: `RE_PIN … add −0.179 deg … confirm the node reports ~0.626 deg`, then `affine per-throw RMS 24.6 mm: OUTSIDE criteria`. The RMS 24.6 mm is inside the 26 mm criterion, so the second line was wrong.

## Diagnosis

**The pin.** Both sittings ran on the base-frame pose path. The 19:23 used offset 0.790° matches heading + κ pooled from the 24 records then held, to 0.0001°.

| Sitting (local) | Session | Plan | Accepted | Node used | Mean bearing ± SE | Lateral ± SE | Mean range | Rotation fit: slope / intercept | Verdict |
|---|---|---|---|---|---|---|---|---|---|
| 2026-10-10 19:23 (FW 7) | `20261010T082544_262394Z` | `local_validation_plan.json`, 40 throws | 28 | 0.790° | −0.278 ± 0.103° | −5.3 ± 2.1 mm | 1149 mm | −0.15 ± 0.47° / −2.3 ± 9.7 mm | INCONCLUSIVE (< 30) |
| 2026-10-10 23:34 (FW 8) | `20261010T123404_756897Z` | `local_validation_plan_range.json` (8 near cells at 600/700 mm, 8 far at 1450/1550 mm, shared bearings 10–38°, 48 throws) | 47 (1 rejected: catch coverage) | 0.804° | **−0.179 ± 0.099°** | −4.2 ± 1.6 mm | 1065 mm | −0.50 ± 0.21° / +5.0 ± 4.2 mm | **RE_PIN −0.179°** |
| pooled (corroboration) | both | — | 75 | (0.804°, first) | −0.216 ± 0.073° | −4.6 ± 1.3 mm | 1096 mm | −0.44 ± 0.19° / +3.7 ± 3.8 mm | (RE_PIN −0.216°) |

How to read the rotation-vs-translation fit at 23:34 (lateral error vs range):
- A pure frame error is a slope only. The slope −0.50 ± 0.21° agrees with the −0.18° rotation within ~1.5σ.
- The intercept +5.0 ± 4.2 mm is consistent with zero.
- The range-weighted plan (near and far cells at shared bearings) was built to separate the two, and it does not reject a pure rotation.
- A residual range-dependent lateral term (slope beyond the bearing mean) is not excluded. It would belong to the affine, not the pin.
- Unlike the 15:00 sitting (intercept +46 ± 11 mm, RE_PIN not applied), nothing here says the bearing rule is reading a translation.

**The affine line.** `analyze_local_calibration.validation_verdict` returns INCONCLUSIVE without a `checks` block when counts are short (47 < 60 accepted, 0 < 10 core). `settle()` read the absent checks as failed.

## Fix

- **Pin (Jugglebot, see external_changes):** 0.208 − 0.179 = 0.029°, applied by the rule per sitting with ≥ 30 throws. The pooled −0.216° is corroboration only. An offline replay of the sitting's own calibration sweep through the real `mocap_node._finalize_calibration` (bag `2026-10-10_23-32-12`, `~/bb_calibration_sessions/yaw_gauge_repin_20261010/`) gives 0.8045° under the old pin, which is the live value. Under the new pin it gives **0.6255°**. Pooled κ moves by exactly −0.179°.
- **`settle_yaw_gauge.py`:** `affine_checks()` returns the report's `checks` when present. Otherwise it evaluates `criteria` against the measured `rms_mm`, `core_rms_mm` (null → not applicable, passes) and `mean_mm`. The output names the numbers and the source, for example `within criteria (RMS 24.6 <= 26, core n/a; computed from criteria (report verdict INCONCLUSIVE))`. It is not a validation verdict, which also needs the counts. When the mean check fails, a second line splits it radial/lateral. The settlement also records `radial_mean_mm` and `affine_checks`.

## Outcome

- The 23:34 sitting now reads: RMS 24.6 mm within criteria (core n/a).
- Mean landing error (−8.1, −8.7) mm is outside the 6 mm per-axis criterion. It is mostly radial (−11.3 ± 2.7 mm short) and only −4.2 mm lateral, so **the re-pin moves only ~3 mm of it**. A short radial bias of ~11 mm is the affine's concern; watch it at the next validation with ≥ 60 throws.
- Tests: `/usr/bin/python3 -m pytest -q test_settle_yaw_gauge.py` → 6 passed (2026-10-11), including the new INCONCLUSIVE-report case.

## Open Questions / Follow-ups

1. **Confirming sweep (owner):** after the Jugglebot branch is merged and deployed, run one sweep with the base markers seen. Do not set `bb_moved`. The node should report ≈ 0.62–0.63°: 0.6255° at the sitting's base heading, 0.6207° at the 23:46 sweep's.
2. The radial −11 mm mean and the slope beyond the bearing are for the next full validation (≥ 60 accepted, core cells), not the pin.
3. `gauge.pin_uncertainty_deg` still reads 0.2° (reported, not used in σ). The landing SE is now ~0.1°; update it with the next template edit if wanted.

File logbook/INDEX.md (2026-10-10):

# Logbook Index

All logbook entries, newest first. Maintained by hand — add a row when you add an
entry. See [README.md](README.md) for the format and [TEMPLATE.md](TEMPLATE.md)
to start a new entry.

## Chapters

Narrative syntheses that read a related block of entries top-to-bottom — the
development, the significant developments/insights, and the open problems. A
chapter is a **reading lens, not a source of record**: it links down to the
entries, which stay authoritative. Open the `.html` in a browser.

| Span | Chapter | Covers |
|---|---|---|
| 2026-06-10 → 2026-06-18 | [01 · V0 Throw Accuracy](chapters/01-v0-throw-accuracy.html) | The spatial (aim-correction) + temporal (release-latency) campaign — all 6 entries below |

## Entries

| Date | Status | Type | Subsystem | Title | Entry |
|---|---|---|---|---|---|
| 2026-10-10 | resolved | investigation | calibration, tooling | Yaw-offset gauge pin settled from landings: 23:34 range-weighted sitting 47 accepted, mean bearing −0.179 ± 0.099° (rotation fit slope −0.50 ± 0.21°, intercept +5.0 ± 4.2 mm) → RE_PIN 0.208 → 0.029° (Jugglebot template, branch bb-yaw-gauge-repin-2026-10-10, not deployed; replay 0.8045 → 0.6255°); 19:23 sitting −0.278 ± 0.103° on 28, pooled −0.216 ± 0.073°; `settle_yaw_gauge.py` evaluates the affine criteria itself on an INCONCLUSIVE report (RMS 24.6 ≤ 26: within, not OUTSIDE; mean −11 mm radial outside); confirming sweep owed | [bb-yaw-gauge-pin-settled](2026-10-10-bb-yaw-gauge-pin-settled.md) |
| 2026-10-10 | resolved | bugfix | firmware, throwing | BB FW 6 hand torque feedforward ×10: the regenerated protocol_config.h took Jugglebot's hand ODrive InputScale::hand_tor = 1000 and CanInterface applies it to BB's hand ODrive S1 (configured 100) — first FW 6 throwing sitting (2026-10-10 14:49): pre-throw kick 350 mm/s from a −3.2 mm rest, retry kicks at the top of the stroke, 3 SPINOUT_DETECTED, strokes 215 vs 236 mm, launch speed −7 %, landings 120 mm short; fix built and flashed 2026-10-10 17:21 (receipt FW 6 -> 7, link check clean); first FW 7 throwing sitting owed (FW 7: BB's own InputScale::bb_hand_* 100/100 and bb_pitch_*, branch bb-fw7-own-hand-scales; S1 SDO scale guard built as FW 8 from the owner's S1 0.6.11-1 table — SDO READ of node 8's input_torque/vel_scale at every hand arm, mismatch zeroes its FF, branch bb-fw8-sdo-scale-guard — FW 7 flashed 17:21 and verified by the 19:23 sitting (hand rest +0.50 mm, no kick, stroke 236 mm, 0 spinouts, launch/predicted 0.956, landings 22.3 mm RMS = FW 5); FW 8 SDO scale guard flashed 21:37, boot verdict MATCH (100/100) on USB serial | [bb-hand-torque-ff-scale](2026-10-10-bb-hand-torque-ff-scale.md) |
| 2026-10-09 | resolved | feature | firmware, calibration | Stamped 100 Hz yaw: BB FW 6 sends YAW_ESTIMATE 0x7D8 per fresh 150 Hz sample; can-bridge FW 28 (Jugglebot) publishes it as bb_yaw on /bb/axis_estimates; headers regenerated (owner-tree delta: +0x7D8 + YAW_S_OFFSET_MM sign); both flashed (bridge 2026-10-10 00:01); on the wire 0x93 at 99.9 Hz, 500/500 paired, yaw_age median 3.0 ms; live BB calibrations run on the stamped yaw since 2026-10-10 (bb_yaw_source auto); the FW 6 build's borrowed hand torque scale was fixed by FW 7/8 the same day (2026-10-10-bb-hand-torque-ff-scale) | [bb-stamped-yaw-100hz](2026-10-09-bb-stamped-yaw-100hz.md) |
| 2026-10-09 | resolved | feature | calibration, tooling | `settle_yaw_gauge.py` + `run_item2_sitting.sh`: settle the constellation estimator's yaw-offset gauge from ~40 corrected throws (pre-registered |mean bearing| ≤ 0.15°); reproduces session B's known −0.50° frame error | [yaw-gauge-settle-tooling](2026-10-09-yaw-gauge-settle-tooling.md) |
| 2026-10-09 | tuned | investigation | calibration, throwing | Full 277-throw local calibration after BB reinstall: 275 accepted, uncorrected 54 mm RMS (bias +44/+9 mm, 8% radial gain); the affine validated on 110 corrected throws at 21.0 mm RMS (the predicted floor) with an 8 mm lateral mean traced to a 0.47° pose-calibration yaw difference between sessions — accepted and deployed (Jugglebot `bb-positive-s-affine-2026-10-09`) | [bb-local-calibration-result](2026-10-09-bb-local-calibration-result.md) |
| 2026-10-07 | resolved | bugfix | calibration, tooling | Pilot extraction 0/10 → 10/10: ball carried rigid-body labels, gravity-only model wrong over full arc (drag + ~1° tilt), apex occlusion | [pilot-trajectory-extraction-fix](2026-10-07-pilot-trajectory-extraction-fix.md) |
| 2026-10-06 | tuned | feature | calibration, tooling | Refill-aware analysis and 331-throw synthetic validation | [local-calibration-analysis](2026-10-06-local-calibration-analysis.md) |
| 2026-10-05 | tuned | feature | calibration, tooling | Mirrored-hand simulation and randomized local two-ball calibration capture | [mirrored-hand-local-calibration](2026-10-05-mirrored-hand-local-calibration.md) |
| 2026-09-30 | in-progress | investigation | firmware, throwing | Layer C yaw settle confirm gains a sample-history term (FW 5): 15 samples (100 ms) in-band + 12 deg/s rate replaces the instantaneous 3 deg/s check that a settled axis's own encoder dither could trip; 4 of 5 R5-sitting NOT_SETTLED refusals were dither, not motion; built, not yet flashed | [yaw-settle-history-term](2026-09-30-yaw-settle-history-term.md) |
| 2026-09-28 | in-progress | feature | firmware, tooling | Firmware update over CAN — the Platform receiver ported to BB, with a safety park (yaw e-stop, pitch ≥ 80°, ODrives IDLE); every session ends in a reboot. Flown: BB FW 2 over CAN (1 → 2, 75.8 s, 0 rewinds), then FW 3 (2 → 3, 56.3 s after the host's sector pause 0.5 → 0.12 s); pitch-raise park branch unexercised; afternoon: FW 4 over CAN in 36.2 s (bridge FW 22, pipelined DATA) | [bb-firmware-update-over-can](2026-09-28-bb-firmware-update-over-can.md) |
| 2026-06-23 | tuned | feature | firmware, throwing, tooling | Loud command-outcome channel (CMD_RESULT) + bb/throw ROS2 action — Phase 2; generic firmware→host outcome relay (CAN1→UDP→action); hardware-validated 2026-06-24 (5/5) | [loud-command-outcome-channel-cmd-result](2026-06-23-loud-command-outcome-channel-cmd-result.md) |
| 2026-06-21 | tuned | feature | firmware, throwing | Throw settle-gates — loud + guaranteed-on-aim throws; Phase 1 (A predictive + C fire-time confirm + serial) hardware-validated; Phase 2 (loud-to-host channel) deferred | [throw-settle-gates-loud-on-aim](2026-06-21-throw-settle-gates-loud-on-aim.md) |
| 2026-06-18 | resolved | investigation | throwing, firmware, calibration, timing | Temporal accuracy resolved (≈44 ms → <10 ms): aim-correction (spatial) + measured release-latency offset (temporal); kinematic-ID & feedforward root-fixes ruled out | [temporal-accuracy-resolved-fractured-solution](2026-06-18-temporal-accuracy-resolved-fractured-solution.md) |
| 2026-06-17 | resolved | investigation | throwing, firmware, calibration | Release-lag fix validated on hardware (δ 140→44 ms); residual is a +3° steeper / +10% hot launch | [release-lag-fix-validated-launch-discrepancy](2026-06-17-release-lag-fix-validated-launch-discrepancy.md) |
| 2026-06-12 | resolved | investigation | throwing, timing, firmware | Temporal "warm-up drift" is a clock-sync artifact (bridge time-master re-acquisition slew), not a thrower effect — root-caused + fixed (2026-06-16) | [temporal-warmup-drift](2026-06-12-temporal-warmup-drift.md) |
| 2026-06-11 | resolved | investigation | throwing, timing, firmware | Release-lag root cause confirmed — two decel-zero mechanisms cancel; 2-line fix (deployed + validated 2026-06-17) | [release-lag-firmware-analysis](2026-06-11-release-lag-firmware-analysis.md) |
| 2026-06-10 | resolved | feature | calibration, throwing, timing | Temporal-accuracy test protocol (v1) + catching-cone uplink plumbing | [temporal-accuracy-protocol](2026-06-10-temporal-accuracy-protocol.md) |
| 2026-06-10 | resolved | feature | calibration, throwing, tracking | Throw aim-correction (2D affine) validated on hardware — ~84% error reduction | [throw-aim-correction-validated](2026-06-10-throw-aim-correction-validated.md) |
| 2026-05-24 | superseded | bugfix | firmware | Axis-settled lead-time gate in executeThrow_ (settle-by-release, silent) — superseded by 2026-06-21 settle-gates | [bb-axis-settled-gate](2026-05-24-bb-axis-settled-gate.md) |

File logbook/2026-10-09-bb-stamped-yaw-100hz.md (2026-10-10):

---
title: Stamped 100 Hz yaw — BB FW 6 sends YAW_ESTIMATE (0x7D8) for /bb/axis_estimates
type: feature
date: 2026-10-09
status: resolved
related_entries:
  - 2026-10-09-bb-local-calibration-result
files_changed:
  - ball_butler_main/platformio.ini
  - ball_butler_main/scripts/bb_link_check.py
  - ball_butler_main/CanInterface.cpp
  - ball_butler_main/CanInterface.h
  - ball_butler_main/Proprioception.cpp
  - ball_butler_main/Proprioception.h
  - ball_butler_main/ball_butler_main.ino
  - ball_butler_main/BallButlerConfig.h
  - ball_butler_main/FwUpdate.h
  - ball_butler_main/protocol_config.h
  - ball_butler_main/hardware_config.h
  - logbook/2026-10-09-bb-stamped-yaw-100hz.md
  - logbook/INDEX.md
external_changes:
  # Jugglebot branch bb-stamped-yaw-100hz (Jugglebot logbook/2026-10-09-bb-stamped-yaw-100hz.md).
  - "Jugglebot: config/protocol_config.yaml + config/generate_config.py (BallButlerCanId::YAW_ESTIMATE 0x7D8, YawEstimateEncoding::vel_res_dps 0.1) + regenerated protocol_config.{h,py} copies"
  - "Jugglebot: config/generate_udp_protocol.py + regenerated udp_protocol.{h,py}, docs/teensy-udp-protocol.md (additive UDP BB_YAW_ESTIMATE 0x93, 24 B; PROTOCOL_VERSION stays 9)"
  - "Jugglebot: ros_ws/src/jugglebot/Teensy_code_canbridge/{ball_butler_state.h,ball_butler_state.cpp,can_buses.cpp,telemetry.cpp,canbridge_config.h} (decode 0x7D8, emit BB_YAW_ESTIMATE paired by t_bridge_us; FW 27 -> 28)"
  - "Jugglebot: ros_ws/src/jugglebot/jugglebot/teensy_bridge_node.py (pair + publish bb_yaw on /bb/axis_estimates)"
  - "Jugglebot: ros_ws/src/jugglebot/jugglebot/can/ball_butler.py (BallButlerYawEstimate, Python mirror of the CAN frame)"
  - "Jugglebot: teensy_link/{__init__,protocol,rpc_args}.py (exports; EXPECTED_BRIDGE_FW_VERSION 28, BB_FW_VERSION_EXPECTED 6)"
  - "Jugglebot: ros_ws/gui/js/udp-traffic.js, tests/ros/test_teensy_bridge_node_bb_yaw.py, tests/ros/test_ball_butler.py, tests/teensy_link/test_protocol_codec.py, tests/firmware/{test_udp_protocol_xlang,test_bb_fw_update_xref}.py"
subsystem:
  - firmware
  - calibration
tags:
  - mocap
  - testing
---

# Stamped 100 Hz yaw — BB FW 6 sends YAW_ESTIMATE (0x7D8) for /bb/axis_estimates

## Summary

BB's yaw reached the Jetson only in the 10 Hz heartbeat. That value is unstamped and lags mocap by a per-session 78–174 ms (`~/bb_calibration_sessions/bb_placement_reinvestigation_20261009/REPORT.md` §Q1, §Q4), so the pose calibration had to fit a latency every session. BB FW 6 now also sends its yaw on CAN1 once per fresh 150 Hz sample. The can-bridge (Jugglebot, FW 28) forwards it, stamped at sample time, as a third name `bb_yaw` (deg, deg/s) on `/bb/axis_estimates` at 100 Hz. The heartbeat is unchanged. Both firmwares compile; **nothing was flashed**. The status stays `in-progress` until the owner flashes the boards and checks the topic. The design, the protocol discussion and the bridge/host side are in the Jugglebot entry of the same name.

## Motivation

See the Summary. The REPORT ranks stamped yaw in `/bb/axis_estimates` as the single biggest robustness gain for the per-session pose procedure. The lag fit then becomes a check.

## Design

**Pitch/hand already arrive this way.** They are ODrives (nodes 7, 8): the bridge hears their 1 kHz `Get_Encoder_Estimates` directly on CAN1 and snapshots them at 100 Hz. Yaw is BB's own AS5047P read in the 150 Hz `YawAxis` ISR, so BB has to put it on the bus.

**CAN frame `BallButlerCanId::YAW_ESTIMATE` = 0x7D8** (generated from Jugglebot `config/protocol_config.yaml`), 8 bytes LE:

| bytes | type | content |
|---|---|---|
| 0–3 | f32 | `yaw_deg`: the same `Proprioception` yaw the heartbeat reports, **unwrapped and untruncated** (the heartbeat wraps to [0, 360) and truncates to 0.01°) |
| 4–5 | i16 | yaw velocity, counts of `YawEstimateEncoding::vel_res_dps` = 0.1 deg/s (the YawAxis EMA velocity × 360) |
| 6–7 | u16 | sample age at TX, µs: `micros64()` now minus the ISR's sample stamp, saturating |

- **Rate.** One frame per fresh sample (deduplicated on the sample timestamp): ~150 Hz, about 1.7 % of the 1 Mbit bus.
- **Priority.** It is the lowest-priority BB id, so it never outranks ODrive traffic. At worst an in-progress frame delays a higher-priority one by one frame time (~0.1 ms).
- **Failure mode.** `sendRaw` is non-blocking (FlexCAN TX queue 16); a full queue drops the frame.

## Implementation

- **`Proprioception`.** It now also stores the yaw velocity: `setYawPV`/`getYawPV`, and `ProprioceptionData::yaw_vel_rps`. The ISR callback in the `.ino` calls `setYawPV`. Its velocity was previously discarded with the note "store it if ever needed".
- **`CanInterface::maybePublishYawEstimate_()`.** It is called from `loop()` after the heartbeat.
- **`CanIds::YAW_ESTIMATE`.** Added in `BallButlerConfig.h`.
- **`FwUpdate.h FW_VERSION` 5 → 6.** This is the flash receipt; Jugglebot `BB_FW_VERSION_EXPECTED` is 6.
- **Headers regenerated from Jugglebot `skill-stack` + this change, into this worktree only.** The owner's `~/Desktop/BallButler` was read, never written. The reconciliation summary is below.

### Regenerated headers vs `main` and vs the owner's working tree

- **`protocol_config.h`**
  - **vs the owner's uncommitted tree:** only this change: `YAW_ESTIMATE = 0x7D8` and the `YawEstimateEncoding` namespace. The owner's `hand_tor` 1000, `can_input_torque_scale` = 283 and the removed `TRAJ_CMD` are identical here.
  - **vs `main`:** those three owner edits plus this change.
- **`hardware_config.h`**
  - **vs the owner's tree:** exactly one line, `BBGeom::YAW_S_OFFSET_MM` −105.65 → **+105.65**. This is Jugglebot's 2026-10-09 positive-s fix, generated after the owner last regenerated.
  - **vs `main`:** the owner's 94-line platform/trajectory delta plus that line. All of it is Jugglebot-platform constants.
  - **Effect on BB firmware: none.** The baseline compile of these headers with the unmodified BB sources succeeded. No BB source reads `YAW_S_OFFSET_MM`; the Jugglebot entry for that fix says "no firmware reads s". The `TeensyTraj` namespace that `main` still carries is gone in both regenerated copies, and nothing in `ball_butler_main` references `TeensyTraj::`.
- **To reconcile,** the owner can discard their two uncommitted header edits in favour of this branch's copies. The branch versions contain them.

## Verification

- 2026-10-09, `pio run -e teensy40_can` (no `-t upload`) in `ball_butler_main/`: **SUCCESS** (`firmware.hex` built). `arm-none-eabi-nm` shows `CanInterface::maybePublishYawEstimate_()`, `Proprioception::setYawPV` and `getYawPV` in the image. The regenerated headers alone, before the firmware edits, also built: **SUCCESS**.
- The bridge/host gate triple is in the Jugglebot entry. BB firmware has no ROS test gate; the compile is its verification.

## Flashing (owner — NOT executed)

1. **BB first, over CAN, through the current can-bridge FW 27.** Bring ROS launch DOWN; BB must be IDLE/ERROR. From the merged BallButler tree, `ball_butler_main/`: `pio run -e teensy40_can -t upload`. Expect `FW version: 5 -> 6`. The upload command resolves `$PROJECT_DIR/../../Jugglebot/tools/teensy_link_bridge.py`, i.e. the owner's `~/Desktop/Jugglebot` checkout, whose BB FW pin then reads 5 (advisory only). The FW 27 bridge drops 0x7D8 harmlessly, so the stack keeps working.
2. **Then the can-bridge over USB.** This is the Jugglebot entry's recipe. Never use a bare `pio run -t upload` or a loader `-s` with both Teensys attached. Run the waiting loader, then a 134-baud touch of `/dev/serial/by-id/usb-Teensyduino_USB_Serial_19942350-if00` only. The teensy-hub is ttyACM0 and the catching cone is ttyACM1.
3. **Check after the host deploy.**
   - `ros2 topic hz /bb/axis_estimates` reads ~100 Hz.
   - `ros2 topic echo /bb/axis_estimates --once` shows `[bb_pitch, bb_hand, bb_yaw]`, with `bb_yaw` ≈ heartbeat yaw within 0.01°.
   - Two names only means BB is still on FW 5, or dark.

USB recovery stays `pio run -e teensy40` + `/home/jetson/bin/teensy_loader_cli --mcu=TEENSY40 -w -v` with a 134-baud touch of BB's by-id path (serial 15970570).

## Open Questions / Follow-ups

- The hardware check above, then `resolved`.
- Switch the pose-calibration fit (Jugglebot `mocap_node`) from heartbeat yaw to `bb_yaw`, keeping the lag fit as a check. Measure `yaw_age_us` (expected mean ≈ 4 ms, an inference from the rates).

## Flash record

- **BB flashed 2026-10-09 23:44–23:45 over CAN** from `main` `c99ce96`: 163 840 B in 25.3 s
  (pipeline depth 4, 0 rewinds, 0 retries, 0 missing acks), VERIFY OK crc32 0xE19F97E4,
  COMMIT OK, reboot, **FW version 5 → 6**. Log: the session's `.bb_flash_20261009.log`
  under `zTesting/throw_testing/accuracy_testing/` (gitignored).
- **Pitfall found on the first attempt.** `platformio.ini`'s `upload_command` runs
  `../../Jugglebot/tools/teensy_link_bridge.py`, and that checkout
  (`mvp-trajectory-bringup`, `e9b75331`) still carries `PROTOCOL_VERSION = 6` and expects
  can-bridge FW 22, while the live bridge is FW 27 on protocol 9. The old client saw the
  bridge's RPC packets but no parseable `HEARTBEAT_T2J` and aborted with "link down?"
  before touching BB (the bridge was streaming ~370 packets/s on 5005 throughout). The
  flash went through with the live checkout's tool:
  `~/Desktop/PDJ_venv/venv/bin/python ~/Desktop/Jugglebot-skills/tools/teensy_link_bridge.py --fw-update .pio/build/teensy40_can/firmware.hex --target bb`
  after `pio run -e teensy40_can` had built the hex. Either point the ini at the checkout
  the live stack runs, or bring `~/Desktop/Jugglebot` up to date before the next CAN flash.
- **Can-bridge flashed 2026-10-10 00:01 over USB** from Jugglebot-skills `skill-stack`
  `02abfe49` (`pio run -e teensy41`, 284 672 B; waiting `teensy_loader_cli --mcu=TEENSY41 -w -v`,
  then a 134-baud touch of the hub's by-id port only; the cone was not on USB). The bridge
  came back reporting **FW_VERSION 28** in its `BRIDGE_IDENTITY` uplink, `BB_AXIS_ESTIMATES`
  still at 100 Hz, link UP. Checked on the raw UDP link with
  `ball_butler_main/scripts/bb_link_check.py` (no ROS needed).
- **BB FW 6 does transmit 0x7D8, from the bags' bridge profile counters** (wire slot 2 = the
  BB bus, `can2_rx`): median 307 frames/s in the 18:56 bag (BB FW 5) against 457 frames/s
  in the 23:49 bag (BB FW 6, bridge still FW 27), i.e. +150 frames/s, the YawAxis sample
  rate. The FW 27 bridge dropped them as designed.
- **BB-side check not possible yet.** At the time of the flash the Ball Butler CAN bus was
  silent (bridge profile wire slot 2: 0 frames/s in either direction, bus health 0; BB's
  ODrives silent too), i.e. BB was powered down after the 23:49 sitting, so no `0x7D8` frames
  and no `BB_YAW_ESTIMATE` (0x93) could be observed. Rerun `bb_link_check.py` with BB on: it
  prints the 0x93 rate (expect ~100 Hz while fresh), the `yaw_age_us` distribution and the
  stamp pairing with `BB_AXIS_ESTIMATES`. Then the ROS topic check above.
- **Link and ROS checks closed 2026-10-10.** With BB powered, `bb_link_check.py` saw `BB_YAW_ESTIMATE` (0x93) at
  99.9 Hz, 500 of 500 paired with `BB_AXIS_ESTIMATES`, `yaw_age_us` median 3.0 ms, max 6.05 ms
  (BB FW 6, bridge FW 28). On the ROS side the 2026-10-10 sittings from 13:45 on ran every BB
  calibration on `yaw source stamped` (bb_yaw lag against mocap −0.2…+2.5 ms per sweep, where the
  heartbeat had lagged 78–174 ms per session), and `bb_yaw_source` defaults to `auto` (stamped
  when it streams) in the live stack since 2026-10-10 (Jugglebot `skill-stack` 308e0b8b). The
  stamped stream's accuracy pay-off is in the Jugglebot logbook
  (`2026-10-10-bb-yaw-offset-spread-stamped-source.md`, `2026-10-10-bb-base-marker-frame.md`).
- **Regression found 2026-10-10 in the first throwing sitting on FW 6:** the regenerated `protocol_config.h`
  carries Jugglebot's hand ODrive `InputScale::hand_tor = 1000`, which `CanInterface` applies to BB's own hand ODrive
  (configured 100) — the hand torque feedforward goes out ×10 (pre-throw kick, 215 mm strokes, spinouts, throws
  ~7 % slow, landings 117 mm short). Tracked in `2026-10-10-bb-hand-torque-ff-scale.md`; this entry stays
  `in-progress` until FW 7 with BB's own hand scales is flashed and a throwing sitting passes.
- **Closed 2026-10-10 21:40:** FW 7 (own hand scales) flashed 17:21 and verified by the 19:23 sitting (all hand criteria
  back to FW 5 values, landings 22.3 mm RMS); FW 8 (SDO scale guard, MATCH at boot) flashed 21:37. The stamped yaw has
  driven every BB calibration since 13:45. Status → resolved.
- **Pitfall fixed.** `platformio.ini`'s `upload_command` (and the header's rehearsal line)
  now point at `../../Jugglebot-skills/tools/teensy_link_bridge.py`, the checkout the live
  bridge was flashed from; the header says why.

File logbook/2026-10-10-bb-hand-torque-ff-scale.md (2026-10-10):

---
title: BB FW 6 sends the hand ODrive ten times the planned torque feedforward — the regenerated protocol_config.h took Jugglebot's hand_tor = 1000 for BB's own hand (configured 100); pre-throw kick, 215 mm strokes, spinouts, throws ~7 % slow
type: bugfix
date: 2026-10-10
status: resolved
phase: "BB accuracy — yaw gauge settlement"
related_entries:
  - 2026-10-09-bb-stamped-yaw-100hz
  - 2026-10-09-bb-local-calibration-result
files_changed:
  - ball_butler_main/protocol_config.h
  - ball_butler_main/CanInterface.h
  - ball_butler_main/CanInterface.cpp
  - ball_butler_main/FwUpdate.h
  - logbook/2026-10-10-bb-hand-torque-ff-scale.md
  - logbook/2026-10-09-bb-stamped-yaw-100hz.md
  - logbook/INDEX.md
external_changes:
  - "Jugglebot branch bb-own-input-scales-2026-10-10 (e0156a7d): config/protocol_config.yaml input_scales + bb_hand_vel/tor 100/100, bb_pitch_vel/tor 1000/1000; regenerated config/generated/protocol_config.{h,py}, ros_ws/src/jugglebot/jugglebot/protocol_config.py and the Platform / can-bridge / CatchingCone protocol_config.h copies; teensy_link/rpc_args.py BB_FW_VERSION_EXPECTED 6 -> 7; logbook/2026-10-10-bb-own-input-scales.md + INDEX.md"
  - "Jugglebot branch bb-s1-sdo-scale-guard-2026-10-10 (b02c44e0, FW 8): config/ODrive config Files/odrive-s1-0.6.11-1_flat_endpoints.json (new, the owner's S1 table); config/protocol_config.yaml endpoints.odrive_s1_0_6_11 + can_input_torque_scale 273, can_input_vel_scale 272, can_node_id 262, fw_version_* 10/11/12, hw_version_* 6/7, commutation_mapper_pos_abs 488 -> 451; regenerated protocol_config.{h,py} + copies; teensy_link/rpc_args.py BB_FW_VERSION_EXPECTED 7 -> 8; logbook/2026-10-10-bb-s1-sdo-endpoints.md + INDEX.md"
commits:
  - aac6a98
  - 17d484a
subsystem:
  - firmware
  - throwing
tags:
  - accuracy
  - repeatability
---

# BB FW 6 hand torque feedforward ×10

## Summary

The first throwing sitting on BB FW 6 (2026-10-10 14:49, `run_item2_sitting.sh`, session
`20261010T035151_835895Z`) showed a new kick of the hand before every throw and before every reload
retry, three `SPINOUT_DETECTED` disarms on the hand drive, strokes ending at 215 mm instead of 236 mm,
and landings 117 mm short. Cause, confirmed in the code: FW 6 regenerated `protocol_config.h` from
Jugglebot `skill-stack`, whose `InputScale::hand_tor` is Jugglebot's hand ODrive Pro scale (1000 since
Jugglebot `75030f73`, 2026-09-15), and `CanInterface` uses that constant for BB's own hand ODrive S1,
which is configured with `input_torque_scale` 100. Every hand torque feedforward has gone out ×10 since
the flash. Fix built (FW 7, BB's own hand and pitch scales, branch `bb-fw7-own-hand-scales`), not yet flashed. Full analysis:
`~/bb_calibration_sessions/hand_jolt_20261010/REPORT.md`.

## Problem

- Owner: the hand jolted from about −3.3 mm to about 0 mm just before each throw, and before the pitch rose
  for a 2nd/3rd reload attempt, never the 1st. First time seen.
- Telemetry (`/bb/axis_estimates` `bb_hand`, 100 Hz): the hand now rests on its bottom stop at −3.21 ± 0.07 mm
  (FW 5: +0.46 mm, 109 of 109 times) and kicks at nominal release − 0.644 s, peak 350 ± 16 mm/s, overshoot
  +1.90 mm, rebound −3.71 mm (40 of 40 throws). The retry kick is at the TOP of the stroke (284 → 288.5 mm at
  284–365 mm/s; FW 5's retry move: 21–57 mm/s). Pitch and yaw do not move at those moments; no ROS command
  arrives then — the kick is frame 0 of the firmware's own throw plan (the 0.1 rev pre-move the planner inserts
  when the start is clamped to ≥ 0, `HandPathPlanner.cpp:40-51, :286`).
- Throws: stroke end 215.5 ± 2.2 mm (FW 5 236.0 ± 0.3), peak hand speed 5–6 % lower, ensemble braking ~−130 m/s²
  (FW 5 ~−55), horizontal launch speed / predicted 0.873 (FW 5 0.943), catch −10 ms vs predicted (FW 5 +27 ms),
  landings −120 ± 30 mm along-range and +29 mm cross-range (FW 5 −1.6 / −8.8 mm).
- `SPINOUT_DETECTED` on bb_hand after throws 18, 30 and 42 (`~/.ros/log/python3_2033231_1791604158337.log:87,130,173`);
  none in any FW 5 log.

## Root Cause

- `ball_butler_main/protocol_config.h:221`: `InputScale::hand_tor = 1000.0f` in FW 6 (`f296441`); FW 5's header
  had 100. The header is generated from Jugglebot `config/protocol_config.yaml` `input_scales`, where `hand_tor`
  is documented as matching `odrive_pro_hand_config.json` — Jugglebot's hand, not BB's.
- `ball_butler_main/CanInterface.h:353-354` sets `kVelScale_ = InputScale::hand_vel`, `kTorScale_ = InputScale::hand_tor`
  and `CanInterface.cpp:234` scales BB's hand `torque_ff` by it. `CanInterface.h:21` still documents the intent:
  "scaled internally by 100.0".
- BB's hand drive (node 8): `Jugglebot-skills/config/ODrive config Files/odrive_s1_bb_hand_config.json`
  `input_torque_scale: 100`, `input_vel_scale: 100`.
- Effect: smooth moves plan 0.0097 N·m → FW 5 sent 1 count (0.010 N·m), FW 6 sends 10 (0.10 N·m); a 3.36 m/s throw
  plans +0.064 / −0.085 N·m → FW 6 asks +0.64 / −0.85 N·m, clipped by the drive's current limit. The home move
  therefore reaches 0 at ~130 mm/s (FW 5 ~30) and, with the streamer dropping to IDLE on the last frame
  (`HandTrajectoryStreamer.h:132`), coasts onto the stop; the planner's pre-move from the stop at ×10 torque is the kick.
- Nothing else in FW 6 touches the hand (BB reads only the `BB*` namespaces of the regenerated headers; the
  `YAW_S_OFFSET_MM` sign is read by no firmware). Bridge FW 28 and the ROS changes since 2026-10-07 do not touch
  the throw or reload command paths. The 0x7D8 yaw frame (lowest CAN priority) cannot make a 10× dynamic change.
- Still owed: a live read of node 8's `axis0.config.can.input_torque_scale` / `input_vel_scale` (odrivetool or SDO).
  100 confirms this chain; 1000 would mean an ODrive/hardware change instead.

## Fix (built 2026-10-10; NOT flashed — flash and a throwing sitting still owed)

Owner's decision: BB-specific keys in Jugglebot's `input_scales`, one pair per axis with unique limits
("each axis with unique limits should have its own set of keys"); Jugglebot's `hand_*` / `leg_*` untouched.

1. Jugglebot `config/protocol_config.yaml` (branch `bb-own-input-scales-2026-10-10`, `e0156a7d`):
   `bb_hand_vel: 100`, `bb_hand_tor: 100` (node 8, ODrive S1, matches `odrive_s1_bb_hand_config.json` and the
   owner's odrivetool read) and `bb_pitch_vel: 1000`, `bb_pitch_tor: 1000` (node 7, ODrive Micro, matches this
   repo's `bb_pitch_odrive_micro_config.json`). Regenerated with `generate_config.py --no-external`; the header
   was copied into `ball_butler_main/` by hand. Its diff against FW 6 is only the four `InputScale::bb_*` lines.
2. BB axis audit of `ball_butler_main/`: the only scaled feedforward is `CanInterface::sendInputPos`
   (`InputScale::` was used nowhere else; no literal 100/1000 scaling elsewhere).
   - Hand (node 8): `HandTrajectoryStreamer` streams vel/tor FF -> `bb_hand_*` (the fix).
   - Pitch (node 7): `PitchAxis` sends `vel_ff = tor_ff = 0` (TRAP_TRAJ), so its bytes are unchanged; it gets
     `bb_pitch_*` so it can never inherit the hand's. Caveat: the pitch JSON is a 2026-03 copy whose `node_id`
     reads 0 (live drive is 7), so 1000/1000 is NOT confirmed on the live drive. Read it back before ever
     sending pitch feedforward.
   - Yaw: brushed DC motor on an H-bridge (PWM, `YawAxis`), not an ODrive: no keys.
   - `sendInputVel` (hand homing) sends float vel/torque, not scaled ints: no keys.
3. `CanInterface::sendInputPos` selects the pair per node: `pitch_node_id_` -> `bb_pitch_*`, every other node
   (in practice the hand) -> `bb_hand_*`. The header comment at `CanInterface.h:21` now says this.
4. `FwUpdate::FW_VERSION` 6 -> 7; Jugglebot `BB_FW_VERSION_EXPECTED` 6 -> 7 (bridge stays 28).
5. **SDO readback guard — FW 8 (built 2026-10-10 on branch `bb-fw8-sdo-scale-guard`, NOT flashed).** Not in
   FW 7: no authoritative S1 0.6.11 endpoint table was available then (FW 7's note: of the five ELFs in
   `~/.cache/odrivetool/firmware/` the one with 726 / 283 is the Pro 0.6.11; `pDOE…` has pos_abs 488 but gpio 675).
   The owner then supplied `odrive-s1-0.6.11-1_flat_endpoints.json` (fw 0.6.11-1, hw 5.2.0, 631 endpoints), now in
   Jugglebot `config/ODrive config Files/`; Jugglebot `b02c44e0` adds the S1 ids to `endpoints.odrive_s1_0_6_11`
   (`can_input_torque_scale` 273, `can_input_vel_scale` 272, `can_node_id` 262, `fw_version_*` 10/11/12,
   `hw_version_*` 6/7) and the regenerated header is copied here (diff: that block only).
   - **488 was not proven.** The S1 block's `commutation_mapper_pos_abs` 488 is
     `axis0.task_times.can_heartbeat.length` in that table (`axis0.commutation_mapper.pos_abs` is 451,
     `axis0.pos_vel_mapper.pos_abs` 429). It never went on the wire from this firmware:
     `CanInterface::isEncoderSearchComplete` is its only user and nothing calls it. Corrected to 451 at the source.
     Only `get_gpio_states` 700 is proven by use (the ball-in-hand poll). `zTesting/sensored_hand_testing/CanInterface.h`
     still hardcodes 488/700 (a test sketch, not touched).
   - **Frame.** RxSdo (cmd 0x04) `[OPCODE_READ=0][endpoint u16 LE][0][0 0 0 0]`, the frame Jugglebot's can-bridge
     builds with `odrive_protocol.h` `encode_sdo_read` for the Pro's torque-scale readback (`rpc.cpp`
     `hand_torque_scale_rpc`); reply TxSdo (cmd 0x05) endpoint in bytes 1-2, value u32 LE in bytes 4-7
     (`decode_sdo_response_u32`). New helper `CanInterface::requestArbitraryParameterRead`. The existing
     `requestArbitraryParameter` sends **OPCODE_WRITE** with a zero payload: the function-invoke idiom for
     `get_gpio_states`; on a property such as `input_torque_scale` (rw) it would write 0. It now carries that warning.
   - **Trigger.** `CanInterface::setRequestedState(hand node, CLOSED_LOOP)` sets a flag (homing, reload, the
     trajectory streamer's arm: every hand arm); `loop()` runs the check. An arm while a check is in flight is
     covered by that check.
   - **Check.** One RxSdo READ in flight at a time: 273, 272, then 262, 10, 11, 12 (log only). Per read 50 ms,
     whole check 250 ms. `handleTxSdo_` hands a reply from the hand node with one of those endpoint ids to the
     guard and does not store it in `arb_param_resp_`, so it cannot displace the ball-in-hand poll's
     `get_gpio_states` reply. No allocation, no blocking, fixed arrays.
   - **Match** (both scales == `bb_hand_tor` / `bb_hand_vel`, 100 / 100): feedforward on, latch cleared; one INFO line
     when the verdict becomes MATCH (`[ScaleGuard] INFO hand node 8 input_torque_scale=100 input_vel_scale=100
     (expected 100/100) MATCH - feedforward ON | drive node_id=8 fw=0.6.11`), silent on repeat matches.
   - **Mismatch** (either scale differs): `ff_disabled_[8]` latched as soon as that reply arrives;
     `sendInputPos` then sends `vel_ff = tor_ff = 0` for node 8 (position-only tracking); a `[ScaleGuard] !!!!! WARNING`
     line with both values on every check while it persists. Cleared only by a check in which both match.
   - **No reply** (a scale missing after its 50 ms): latch left as it was (on at boot; off if an earlier check
     latched it); a `[ScaleGuard] WARNING ... readback incomplete` line on every check.
   - **Host.** USB serial only. The 0x7D1 heartbeat's byte 1 is "error code when ERROR, else 0" in the can-bridge,
     the UDP heartbeat field and `ball_butler.py`; CMD_RESULT (0x7D5) has no fitting command/outcome. No frame changed.
   - **Limits.** (a) Feedforward is on until the first verdict; the first arm after boot is the homing, which sends
     float `set_input_vel` (unscaled), so in practice the verdict lands before any scaled FF, but a streamer arm
     that starts a check sends its first frames before the reply (a few ms). (b) The fw version is printed, not
     gated on: if the drive is not S1 0.6.11-1, 273/272 may name other registers — a read is harmless, and an
     unlikely value reads as MISMATCH (FF off, loud). (c) Only the hand is checked; pitch sends zero FF anyway.
     (d) A mismatch degrades throws (no FF) rather than refusing them.
6. Not done (separate, optional): hold closed loop in `HandTrajectoryStreamer.h:131-134` until the hand stops.

## Verification

- FW 8 build (2026-10-10, branch `bb-fw8-sdo-scale-guard`): `pio run -e teensy40_can` and `-e teensy40` SUCCESS, no
  warnings (the build has no `-Wall`; `CanInterface.cpp` compiled with `-Wall -Wextra` gives 12 warnings, all in
  FlexCAN_T4, the same 12 as FW 7); `firmware.hex` 469 577 bytes, both envs byte-identical, sha256
  `a03524d3…02b05ec`. ELF: `kScaleGuardEndpoints_` = 273, 272, 262, 10, 11, 12. Not flashed; no hardware run.
  Jugglebot `JUGGLEBOT_BALLBUTLER_DIR=~/Desktop/BallButler-fw8`: scoped tests 1088 passed, 1 skipped; `--full` PASS.

- Build (2026-10-10): `pio run -e teensy40_can` and `-e teensy40`: SUCCESS, `firmware.hex` 460 937 bytes (both
  envs byte-identical, sha256 `0ec1f953…10da`). Disassembly: `sendInputPos`'s literal pool holds only `100.0f`
  (0x42c80000) and `1000.0f` (0x447a0000), chosen by a compare against `pitch_node_id_`. Not flashed.
- Jugglebot (2026-10-10, `JUGGLEBOT_BALLBUTLER_DIR=~/Desktop/BallButler-fw7`): scoped firmware / teensy_link /
  protocol_config tests 1698 passed, 1 skipped; `./run_tests.sh --full` PASS. `test_bb_fw_update_xref.py` against
  this repo's main (FW 6) fails until this branch merges — expected.
- Done (offline): FW 6 sitting bag `2026-10-10_14-49-14` and session `20261010T035151_835895Z` against the FW 5
  sessions `20261009T031319_612936Z` and `20261009T002142_931068Z`; scripts and CSVs in
  `~/bb_calibration_sessions/hand_jolt_20261010/`. Code pointers above checked in both repos.
- Pass criteria for the FW 7 sitting: hand rests at ~+0.46 mm (no pre-move); retry move < ~60 mm/s; stroke ends
  at ~236 mm; no spinouts; catch time back to ~+27 ms vs predicted. Then re-run the 40-throw validation.
- **Consequences for the accuracy work:** the 14:49 session's landings (mean −120 / −15 mm, RMS 128 mm) are this
  bug's; `settle_yaw_gauge.py`'s RE_PIN +2.406° from it is NOT applied (its own rotation-vs-translation fit reads the
  lateral error as a translation: slope −0.3 ± 0.6°, intercept +46 ± 11 mm), the pin stays 0.208°, and the aim
  correction is not refitted from it.

### Flash record (2026-10-10 17:20–17:21 local)

- From the merged `main` (`da3bfbe`), `pio run -e teensy40_can -t upload` in `ball_butler_main/` (the ini's
  `upload_command` → `~/Desktop/Jugglebot-skills/tools/teensy_link_bridge.py --fw-update … --target bb`), ROS launch
  down, BB IDLE (state 1) and visible on the bridge's BB bus at 457 frames/s beforehand. DATA 163 840 B in 25.4 s
  (pipeline depth 4; 26 BAD_SEQ rewinds in the first second, 0 window retries, 0 missing acks — FW 5 → 6 had 0
  rewinds), VERIFY OK crc32 0x1595BCA5, COMMIT OK, receipt **`Ball Butler FW version: 6 -> 7`**; 43 s end to end.
- Post-flash `scripts/bb_link_check.py`: bridge FW 28, BB bus 459 frames/s, BB state 1, `BB_YAW_ESTIMATE` 99.8 Hz with
  401/401 stamps paired; hand still reads −0.097 rev (−3.2 mm) — it stays on the stop until the next reload moves it,
  so the behavioural check (rest at ~+0.46 mm after a reload, no pre-throw kick, stroke to ~236 mm, no spinouts) is
  the owner's first sitting on FW 7.
- Jugglebot side merged and installed (`skill-stack` 456fd788: `bb_hand_*` 100/100, `bb_pitch_*` 1000/1000,
  `BB_FW_VERSION_EXPECTED` 7); `tests/firmware/test_bb_fw_update_xref.py` + `test_udp_protocol_xlang.py` against this
  tree: 49 passed; `generate_config.py --check`: CONFIG FRESH, no external drift.

## Open Questions / Follow-ups

- ~~The live node 8 scale read~~ — owner read `input_torque_scale` = 100 with odrivetool, 2026-10-10.
- ~~A similar borrowed constant elsewhere~~ — none: `InputScale::` had one use (`CanInterface.h:353-354`).
- Owed: flash FW 7 (receipt `FW version: 6 -> 7`), then the FW 7 throwing sitting against the pass criteria above.
- ~~Follow-up: the S1 torque-scale SDO readback at hand arm~~ — built as FW 8 (Fix item 5), flash owed: receipt
  `FW version: 7 -> 8`; at the first hand arm (boot homing) USB serial should show the `[ScaleGuard] INFO ... MATCH`
  line with `node_id=8 fw=0.6.11`.
- Follow-up: read node 7's `input_vel_scale` / `input_torque_scale` and refresh `bb_pitch_odrive_micro_config.json`
  (node_id 0 in the saved copy).

## Outcome (2026-10-10 evening)

- **FW 7 verified on hardware** (sitting 2026-10-10 19:23, session `20261010T082544_262394Z`, 40 throws; analysis
  `~/bb_calibration_sessions/fw7_sitting_20261010/REPORT.md`): hand rest before a throw +0.50 mm (FW 6 −3.21, FW 5 +0.43);
  pre-throw kick none (max 5.5 mm/s; FW 6 350 mm/s on 40/40); reload-retry move 23–33 mm/s (FW 6 284–365); stroke end
  236.05 mm (FW 6 215.55, FW 5 236.05); spinouts 0 (FW 6 3); launch speed / predicted 0.956 (FW 6 0.873, FW 5 0.943);
  catch time vs predicted +26.8 ms (FW 6 −10.1, FW 5 +27.2). Landings (28 accepted): mean (+4.0, −4.6) mm, RMS 22.3 mm,
  along-range +2.7 ± 3.5 mm — the FW 6 short-fall is gone and the result is indistinguishable from FW 5. The 12
  rejections were mocap frame loss under Jetson load (Jugglebot logbook `2026-10-10-mocap-frame-loss-under-load`), not BB.
- **FW 8 (the SDO scale guard) flashed 2026-10-10 21:36–21:37** from `main` 10f01ac over CAN (166 912 B in 26.0 s,
  0 rewinds, VERIFY OK crc32 0xC472A4E5, receipt `FW version: 7 -> 8`), with BB's USB serial captured through the
  reboot (`~/bb_calibration_sessions/hand_jolt_20261010/fw8_flash_serial_20261010.log`): at the boot homing arm
  `[ScaleGuard] INFO hand node 8 input_torque_scale=100 input_vel_scale=100 (expected 100/100) MATCH - feedforward ON |
  drive node_id=8 fw=?`, then `[Home] node=8 homed`, `BOOT -> IDLE`; no GPIO-poll timeouts. The S1 endpoint ids 273/272
  therefore fit the live drive. Cosmetic follow-up: the fw-version reads (endpoints 10/11/12, log only) came back `?`
  within the check's budget — not needed for the verdict.
- Post-flash `bb_link_check.py`: bridge FW 28, BB on the bus, stamped yaw paired. Jugglebot side at `skill-stack`
  9f2eecdb (`BB_FW_VERSION_EXPECTED` 8). Status → resolved. The S1 table is committed in Jugglebot
  `config/ODrive config Files/odrive-s1-0.6.11-1_flat_endpoints.json`.

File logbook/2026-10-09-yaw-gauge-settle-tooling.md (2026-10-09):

---
title: Tooling to settle the constellation estimator's yaw-offset gauge from corrected throws
type: feature
date: 2026-10-09
status: resolved
related_entries:
  - 2026-10-09-bb-local-calibration-result
files_changed:
  - zTesting/throw_testing/accuracy_testing/settle_yaw_gauge.py
  - zTesting/throw_testing/accuracy_testing/test_settle_yaw_gauge.py
  - zTesting/throw_testing/accuracy_testing/run_item2_sitting.sh
  - zTesting/throw_testing/accuracy_testing/LOCAL_CALIBRATION.md
  - logbook/2026-10-09-yaw-gauge-settle-tooling.md
  - logbook/INDEX.md
external_changes:
  - "Jugglebot: branch bb-constellation-yaw-2026-10-09 (mocap pose calibration from the whole sweep with a fitted latency; gauge pinned to session A's frame) — pending merge"
  - "Jugglebot + BallButler: branch bb-stamped-yaw-100hz (BB yaw in the stamped 100 Hz /bb/axis_estimates stream) — pending merge and flash"
subsystem:
  - calibration
  - tooling
tags:
  - accuracy
  - mocap
---

# Tooling to settle the constellation estimator's yaw-offset gauge from corrected throws

## Summary

Two analyses on 2026-10-09 (`~/bb_calibration_sessions/yaw_offset_investigation_20261009/`
and `~/bb_calibration_sessions/bb_placement_reinvestigation_20261009/`) showed that BB's
stored yaw offset came from one anchor marker's angle about the sweep's fitted axis point
(118 mm radius, 0.49° per mm) and jumped 0.47° between two sessions with BB untouched,
while the whole-sweep constellation fit with a fitted heartbeat latency repeats to 0.03°
per sweep. The estimator being implemented in Jugglebot reports its offset in session A's
frame through a gauge pinned from recorded data, uncertain by about ±0.2°. This tooling
settles that pin with throws.

## Motivation

A yaw-offset error e turns every corrected landing's bearing about BB's yaw axis by −e in
the frame the node used; session B measured −0.50 ± 0.05° for a +0.47° error. Forty
corrected throws therefore pin the gauge to about ±0.1° (per-throw lateral scatter ~10 mm
at ~1 m), without a refit of the affine.

## Design

- `settle_yaw_gauge.py <session>/session.json`: from `analysis/extraction.json`, per-throw
  bearing error (landing − desired, in the session's frame), its mean ± SE, the lateral mean,
  a rotation-versus-translation regression as a diagnostic, and the implied frame offset
  `used + mean_bearing`. Pre-registered rule: ≥30 accepted throws; |mean bearing| ≤ 0.15°
  → `FRAME_CONFIRMED`, else `RE_PIN` with the delta to add to `gauge.pinned_yaw_offset_deg`
  in the Jugglebot template resource. Uncorrected sessions are refused (their aim bias
  would be read as a frame error). The affine's RMS checks from `extraction_report.json`
  are reported alongside.
- `run_item2_sitting.sh [N]`: preflight (`--check-only`), the throws (`--limit N`,
  `--apply-correction`, solver `cb09095e`), `--extract-only`, then the settle script.

## Implementation

See `LOCAL_CALIBRATION.md` § "Settling the yaw-offset gauge". The sign convention is
derived in the script's docstring and pinned by a synthetic test.

## Verification

- `/usr/bin/python3 -m pytest test_settle_yaw_gauge.py -q` (2026-10-09): 5 passed, including
  the real-data regression on session B `20261009T031319_612936Z`: mean bearing
  −0.496 ± 0.053°, implied frame offset 0.184° against the 0.208° the affine was fitted in,
  verdict `RE_PIN` with delta −0.496°.
- The full calibration test set: see the commit message.

## Open Questions / Follow-ups

- The sitting itself (merge and build the sweep estimator first; flashing the stamped-yaw
  firmware is optional for it, the estimator fits the latency).
- BB's reported-to-physical yaw relation is not 1:1 (markers turn ~2.3° less than the
  encoder over 0→125°); the affine absorbs it inside the calibrated region. Not corrected.
- Fixed markers on BB's base and in the room (owner, when possible) to separate a BB or
  encoder change from a QTM frame change.

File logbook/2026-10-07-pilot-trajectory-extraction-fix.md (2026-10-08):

---
title: Pilot trajectory extraction — labelled ball, wrong flight model, apex occlusion
type: bugfix
date: 2026-10-07
status: resolved
related_entries:
  - 2026-10-06-local-calibration-analysis
  - 2026-10-05-mirrored-hand-local-calibration
files_changed:
  - zTesting/throw_testing/accuracy_testing/analyze_local_calibration.py
  - zTesting/throw_testing/accuracy_testing/test_analysis_local_calibration.py
  - zTesting/throw_testing/accuracy_testing/simulated_calibration_validation.json
  - zTesting/throw_testing/accuracy_testing/LOCAL_CALIBRATION.md
  - zTesting/throw_testing/accuracy_testing/run_local_calibration.py
  - zTesting/throw_testing/accuracy_testing/test_local_calibration.py
  - logbook/2026-10-07-pilot-trajectory-extraction-fix.md
  - logbook/INDEX.md
commits:
  - 308497e
  - a24ecda
  - (pre-flight follow-up)
subsystem:
  - calibration
  - tooling
tags:
  - mocap
  - ballistics
  - testing
---

# Pilot trajectory extraction — labelled ball, wrong flight model, apex occlusion

## Problem

The first complete ten-throw hardware pilot
(`~/bb_calibration_sessions/20261007T043306_968166Z`, `--schedule-to-mocap 0.3 -0.6`,
all ten firmware OK) extracted **0/10** throws. Throws 0, 1 and 9 failed with
"no continuous launch-to-catch ballistic fit passed quality gates", and throws 2–8 with
"no launch-associated observations". The 331-throw synthetic campaign had
passed because it assumed unlabelled, fully visible, gravity-only flights with nominal timing.
All analysis was offline; no hardware was commanded.

## Root Cause

Before touching the extractor, I checked each assumption against the recording:

1. **Timing and clocks were fine.** `/mocap_data.stamp` is QTM frame time, from the
   `Jugglebot-skills` checkout's `mocap_node`:
   - Stamp spacing is quantised at 3.33 ms (300 Hz QTM, republished by a 200 Hz timer, so some stamps repeat).
   - Stamp minus receipt time: median −1.7 ms, range ±23 ms; slope 0.99993.
   - `BallButlerThrowCmd.throw_time` is a *relative* delay. The canbridge adds it to its synced wall clock
     (`ball_butler_protocol.h`), and the runner subtracts the 44 ms release latency, so
     `nominal = dispatch + 3 s` is consistent with the code.
   - Firmware OK arrived 38–55 ms after nominal release.
2. **The reader dropped the ball (primary cause).** QTM gave the thrown ball rigid-body labels:
   - `Base - 1` covered the ball at rest in the hand and the entire flight of throws 0, 2 and 4.
   - `Base - 3/4/7` covered parts of other flights.
   - The reader kept only empty-label markers.
3. **The flight model was wrong.** With every marker kept, the old extractor still rejected 10/10:
   - A gravity-only arc leaves smooth residuals: about ±10 mm mid-flight and 30–50 mm at the ends.
   - A free constant-acceleration fit gives about (0, +140, −9 560) mm/s² on every throw, whatever its direction.
   - Quadratic drag plus a free effective-gravity vector fits every throw to 1.3–2.3 mm RMS,
     with g_eff ≈ (+80, +170, −9 740) mm/s², about 1.1° off the frame z axis.
     BB's calibration reports 0.87° axis tilt.
   - A frame tilt and spin (Magnus) effects cannot be separated with this data. The tilt is recorded as an observation, not acted on.
4. **The launch gate assumed the wrong time and position.**
   - The arc passes within 5–11 mm of the predicted release point, but 40–57 ms *before* nominal release.
   - At nominal release the ball is therefore 85–150 mm higher than predicted, which tripped the 150 mm position-at-t=0 gate.
5. **Apex occlusion.** The ball is often unseen from about 0.1–0.3 s until about 0.4–0.47 s.
   Throws 6 and 9 have no ballistic points before roughly 0.37–0.40 s. This defeated
   the "≥10 points in 0–350 ms" seed and the 80 ms whole-track gap limit.

## Fix

Agreed with the owner before implementation. `analyze_local_calibration.py`:

- **Reader:** keeps all markers, whatever their label. Exactly repeated frame stamps are counted once.
- **Seeds:** anchored at the predicted *release position* at a few arc times and free in velocity, so the
  landing is never pulled toward the target.
- **Launch gate:** the arc's closest approach is ≤100 mm from the predicted release position, at an arc time within ±0.10 s.
- **Free-flight gate:** a per-axis constant-acceleration fit within 6 % of g. The 8 mm inlier, 5 mm RMS, 30-frame and 0.25 s gates are unchanged.
- **Occlusion:** earlier gaps up to 0.45 s are bridged. The segment through the catch plane
  must be continuous (≤80 ms gaps) for ≥0.25 s and observed to within 15 ms of the crossing.
- **Measurement:** catch-plane XY comes from a local fit over −150/+40 ms around the crossing, with the track's acceleration held fixed.
- **Rejections:** each one carries the furthest gate reached plus per-gate counts in `extraction.json`.
- **Ambiguity:** checked between distinct tracks (<50 % shared frames).

Pre-registered criterion: local crossings must agree within 3 mm with an independent
drag + tilted-gravity ODE fit, otherwise reject. Result: 0.9–2.1 mm on all ten throws, so it passed.

## Verification

Pilot, using the CLI with `--extract-only --out …/analysis_fixed`. The original `analysis/`, `session.json`
and bag are untouched; the historical `recording_needs_review` flag is retained.
Errors are measured catch-plane XY minus the commanded target, in mocap mm.

| throw | cell | catch XY | error | samples | final segment (s) | max gap (s) | fit / local RMS (mm) | arc offset |
|---|---|---|---|---|---|---|---|---|
| 0 | 41 | (−214.3, −104.3) | (+22.9, −3.7) | 181 | −0.018–0.915 | 0.013 | 2.53 / 0.37 | −48 ms |
| 1 | 131 | (−345.4, 535.8) | (+44.9, −4.2) | 125 | 0.367–0.927 | 0.236 | 2.93 / 0.48 | −49 ms |
| 2 | 92 | (−371.2, 87.6) | (+19.2, −11.8) | 168 | −0.016–0.925 | 0.017 | 3.22 / 0.26 | −57 ms |
| 3 | 51 | (678.3, −84.7) | (+87.4, +15.9) | 133 | 0.439–0.933 | 0.157 | 2.72 / 0.48 | −48 ms |
| 4 | 60 | (155.6, −57.5) | (+55.3, −6.9) | 150 | 0.143–0.936 | 0.187 | 2.58 / 0.53 | −45 ms |
| 5 | 139 | (243.2, 582.8) | (+92.9, +42.8) | 148 | 0.435–0.942 | 0.173 | 2.82 / 0.53 | −40 ms |
| 6 | 78 | (−576.1, 48.2) | (+14.2, −1.2) | 107 | 0.402–0.929 | 0.363 | 2.61 / 0.81 | −50 ms |
| 7 | 64 | (712.3, −37.9) | (+121.4, +12.7) | 134 | 0.456–0.923 | 0.186 | 3.38 / 0.37 | −48 ms |
| 8 | 115 | (447.3, 191.7) | (+56.4, +4.8) | 144 | 0.064–0.924 | 0.107 | 3.18 / 0.41 | −53 ms |
| 9 | 39 | (−568.0, −105.0) | (+22.3, −4.4) | 116 | 0.353–0.923 | 0.290 | 2.39 / 0.47 | −56 ms |

All ten are accepted. The mean miss is (+53.7, +4.4) mm, RMS 65.9 mm, and the X miss grows with target X.
These are uncorrected misses from ten throws, not an accuracy claim. Ten cells are below the
affine's 12-cell minimum by design, so no correction was fitted.

Synthetic campaign, re-run with the new extractor:
- 331/331 throws recovered; extraction vs truth 0.47 mm RMS (was 0.24).
- Correction vs true inverse 0.78 mm RMS.
- Fresh core RMS 24.36 → 10.09 mm.

Tests: 28 pass under the PDJ venv. The new regression tests cover a hardware-shaped flight,
a labelled ball through the MCAP reader, a non-BB arc rejected at the launch gate, and an unobserved crossing rejected.
The hardware-shaped and MCAP tests fail on the previous extractor.

## Open

- **Arc passes the release point about 48 ms early.** One possible explanation is the host's 44 ms latency compensation
  double-counting after the 2026-06 firmware release-lag fix. Another is a release-geometry offset
  along the stroke. Settle it with the direct sensor: the hand position in the bag's `/bb/axis_estimates` against the ball arc.
- **About 1.1° effective-gravity tilt plus drag.** This is unresolved: it could be a frame tilt or spin. The production solver assumes gravity-only flight with frame z vertical.
- **Model coverage.** The simulator still models gravity-only, visible-launch flights. The hardware-shaped
  cases live in unit tests. Edge cells (larger range, higher apex) are untested on hardware;
  watch the per-gate rejection diagnostics in the full campaign.
- **Runtime.** About 1.2 s per throw for synthetic JSONL analysis; about 27 s for the ten-throw pilot, which is dominated by MCAP decoding.

## Follow-up: false "mocap receive gap" stop (second pilot, QTM recording)

Session `20261007T051301_800928Z`, run with a simultaneous QTM recording,
stopped at throw 6: "Mocap receive gap exceeded 100 ms" (0.102 s). The bag shows
no gap. Receipt gaps were ≤13 ms and QTM stamp gaps ≤21 ms on every throw, and the clean
pilot was the same (≤17 ms). Yet the runner reported 78–99 ms on *every*
throw of both sessions. The guard measured spacing between the runner's own
callbacks. Each `session.json` checkpoint costs ~23 ms, growing with the session. Several in a row
around dispatch and result, with a depth-5 subscription, stall the callbacks by
~100 ms. The full campaign would have tripped it regardless of QTM. The QTM
"timestamp discontinuity" warning came at 16:12:54, before the first throw, and is harmless.

Fix (agreed): a deep (100) best-effort subscription, and `StreamMonitor` judges
continuity from QTM source stamps. A >100 ms stamp gap, a backwards step or a zero
stamp rejects **that throw's capture** (`capture_rejected`) and the session
continues. Three consecutive rejections, or mocap stale for >1 s, still stop the session.
The analysis lists rejected or incomplete captures. Replaying both bags' real
stamps: max 13–21 ms, no rejections. The second session's five complete throws all
extract (fit RMS 2.1–3.1 mm, arc offset −49 to −53 ms, repeating the pilot).
31 tests pass (PDJ venv; system 3.8 skips the MCAP test).

## Follow-up: pre-flight review for the full campaign (2026-10-09)

A fresh agent walked the pipeline offline and read-only. It found no definite blocker; the
high-risk items were all fixed here. Agreed with the owner.

- **Wrong solver risk (verified).** `~/.zshrc` sources `~/Desktop/Jugglebot/ros_ws/install`. Both pilots
  imported `Jugglebot-skills`'s `throw_ballistics.py`. The two differ (sha256 3b4695b4… vs
  bbb80fa5…, 279 vs 277 feasible, up to 0.5° pitch, 84 mm/s speed) and would fail
  silently. The runner now prints the solver path and sha. The new `--expect-solver-sha` aborts on a mismatch,
  and `--resume-from` requires the same sha.
- **No resume.** `--resume-from SESSION_JSON` (repeatable) skips entries already
  released and cleanly captured, and re-throws the rest. Plan, s, frame translation and solver must
  match. The analyser pools several sessions, using per-session BB pose and `K:IDX` exclusions.
- **Stray keystrokes.** The refill prompt flushes earlier keystrokes and re-prompts on junk instead of stopping.
- **Duration.** About 10.4 s per throw cycle and a 35 s refill give ~66 min for 277 throws.
  QTM runs as a continuous capture, ended after the runner closes its bag.
- **Lower risk.** The carry-on decision is now a tested `capture_decision()`. The redundant post-dispatch
  checkpoint was removed (each save costs ~55 ms at 277 rows). The analyser skips and counts
  bad-clock frames instead of aborting.

Real pilots pooled through the new CLI: 15 accepted. The stopped throw is listed as
"capture incomplete". Originals are unchanged (md5). 35 tests pass (system 3.8 skips the MCAP test).
Still untested on hardware: the carry-on path and resume. The simulator still uses
gravity-only flights.

## Follow-up: retry yaw NOT_SETTLED aborts (2026-10-09)

Two full-campaign attempts (`20261008T233311_570387Z`, 20 throws; `20261008T233839_272481Z`,
resumed, 6 throws) stopped on `THROW_ABORTED_NOT_SETTLED (axis=YAW)`. The yaw errors were
−0.70° and −0.83°, inside the 1.0° tolerance, so the 100 ms settled-history term probably refused them. The commanded
yaws were small (2.8°, 4.9°), but 5.5°/6.0° throws succeeded, so the abort is not
deterministic. Firmware `handleThrowing_` aborts before hand motion with the ball
retained. Both bags show THROWING → IDLE with `ball_in_hand` True 0.16 s later.

The runner now re-sends that entry (YAW or BOTH axis only) up to `--max-attempts` (3).
Each attempt is its own row. An entry still failing after the last attempt is
recorded in `abandoned_throw_indices` and skipped. Every other refusal still stops the session.
Also seen: in `233311` throw 15 the capture was rejected for a real 117 ms QTM source-stamp
gap while receipt gaps stayed ≤49 ms. QTM itself skipped frames. The carry-on path
worked as designed on hardware.
Open: whether low-yaw targets abort systematically. Watch `abandoned_throw_indices`.

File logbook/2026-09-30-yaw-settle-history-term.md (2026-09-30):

---
title: Layer C yaw settle confirm gains a sample-history term (FW 5): dither on a settled axis stops tripping the gate
type: investigation
date: 2026-09-30
status: in-progress
phase: "R5 sitting 1 / BB FW 5"
related_entries:
  - 2026-06-21-throw-settle-gates-loud-on-aim
  - 2026-09-28-bb-firmware-update-over-can
files_changed:
  - ball_butler_main/BallButlerConfig.h (YAW_RATE_TOL_DPS 3.0 -> 12.0, new YAW_SETTLED_MIN_SAMPLES = 15, comment rewrite, stale logbook-date label fixed 06-19 -> 06-21)
  - ball_butler_main/YawAxis.h (Telemetry::settled_samples, settled_samples_ member)
  - ball_butler_main/YawAxis.cpp (ISR settle-history counter, begin()/readTelemetry() wiring, hard-limit fault path resets the counter)
  - ball_butler_main/HandTrajectoryStreamer.h (yaw_settled_min_ member + arm() parameter, yaw_ok gains the history term, serial abort line reports settled=N/required)
  - ball_butler_main/StateMachine.cpp (the one arm() call passes YAW_SETTLED_MIN_SAMPLES explicitly)
  - ball_butler_main/FwUpdate.h (FW_VERSION 4 -> 5, receipt comment)
external_changes:
  - "Jugglebot (skill-stack worktree): teensy_link/rpc_args.py (BB_FW_VERSION_EXPECTED 4 -> 5)"
subsystem:
  - firmware
  - throwing
tags:
  - safety
  - throw
  - testing
---

# Layer C yaw settle confirm gains a sample-history term (FW 5)

## Summary

5 of 19 `bb/throw_at_target` dispatches at the R5 sitting (2026-09-30) refused
`THROW_ABORTED_NOT_SETTLED`. Four sat on a flat, sub-0.4 deg plateau and were refused
by encoder dither on an already-settled axis crossing the old instantaneous
`YAW_RATE_TOL_DPS = 3.0` bound, not by real motion. FW 5 adds a 15-sample (100 ms at
150 Hz) in-band error history alongside a widened 12 deg/s rate bound, so a settled
axis's dither can no longer trip the gate while a genuine traverse still does. Built
(2026-09-30, 18:31, SUCCESS in 5.04 s) and flashed over CAN at 22:45 (receipt 4 -> 5). The investigation's own
starting premise, that the fifth refusal (throw #1) was a distinct late-convergence
case the fix must still catch, does not survive a 150 Hz replay of its own trace: see
Discussion.

## Symptoms

R5 sitting 1 (2026-09-30, bag `~/Desktop/rosbags/2026-09-30_16-20-05`) made 19
`bb/throw_at_target` dispatches to Jugglebot: 14 `OK`, 5 `THROW_ABORTED_NOT_SETTLED`.
Four of the five (throws #3, #5, #10, #12) sat on a flat, sub-0.4 deg peak-to-peak
position plateau for the full 1.5 s before the fire-time check, with error at the
check instant in the same +0.26 to +0.48 deg band as more than half of the accepted
throws, and 10 Hz-derived rate magnitudes (1.10 to 3.18 deg/s) overlapping accepted
throws #14 (3.89 deg/s) and #15 (2.33 deg/s). Nothing in the position trace told the
four plateau refusals apart from the accepted throws around them.

The fifth, throw #1, looked different at first: a real, large, monotonic yaw
convergence from -4.27 deg error down to inside tolerance in the final 0.3 to 0.4 s
before the check, read initially as a Layer A lead under-estimate rather than gate
noise, and treated as a case any fix must still be able to refuse.

## Diagnosis

`YawAxis`'s yaw error and rate come from a 150 Hz finite difference of the AS5047P
absolute encoder (16384 counts/rev, so 1 count = 360/16384 = 0.02197 deg), EMA-filtered
at alpha = 0.3. One encoder count of jitter between two consecutive 150 Hz samples
already implies a raw velocity of 0.02197 x 150 = 3.296 deg/s, above the old
`YAW_RATE_TOL_DPS = 3.0`, before any filtering. A single isolated count only pushes the
filtered value to 0.3 x 3.296 = 0.99 deg/s, so a one-count flicker never tripped the
old gate. What trips it is a kick of 4 or more counts in one sample, or 2 counts in
each of two adjacent samples (confirmed by the offline gate model,
`scratchpad/probe_bb_fw5_gate.py`, probe A).

The yaw loop is pure P (Kp = 300, Ki = 0, Kd = 0, `hardware_config.h:389-391`), which
has no mechanism to null a steady-state friction offset, so it parks at whatever small
residual error balances Kp times error against static friction. Below the PWM
deadband, the sigma-delta dither (`YawAxis.cpp:704-725`, `deadzone_compensate()`)
accumulates sub-threshold command magnitude every tick and fires a single
full-magnitude `PWM_MIN` pulse once the accumulator crosses threshold: a real, brief
motor kick, sized right at the old tolerance boundary by construction, not noise in
the instrumentation sense. That is the plateau refusals' mechanism: a settled axis's
own dither crossing an instantaneous rate check that was built to catch a traverse.

This claim is bounded by what the bag can show: the only yaw signal relayed to the
Jetson is `bb_yaw_deg` position at 10 Hz (`/bb/heartbeat`); the firmware's own 150 Hz
`vel_rps` never reaches the host. A 10 Hz first difference cannot resolve a
single-ISR-tick kick, so the dither mechanism is inferred from the code and the
offline probe, not measured live at 150 Hz. The mechanism is still unmeasured on
hardware; see Outcome for what would close that gap.

## Discussion

**Withdrawn premise: throw #1 is not a distinct case.** The investigation started
from the sitting's own framing, that throw #1 was a genuine late-converging throw a
fix must still be able to refuse, separately from the four dither false positives.
Replaying #1's own 10 Hz trace at 150 Hz (probe C) withdraws that. The yaw entered the
+/-1 deg band at t = -0.79 s, about 0.7 s before the recorded check, and from
t = -0.42 s sat flat at error -0.45 to -0.51 deg. At the recorded check instant:
error +0.45 deg, rate 0.58 deg/s, settled_samples = 116. FW 5 passes this throw, and
so would FW 4 on the same smooth trace (FW 4's last refused instant on this replay is
t = -0.798 s). Throw #1's real refusal at the check was the same unseen 150 Hz dither
as the four plateau cases, riding the tail of a convergence that had already finished
roughly 0.7 s earlier, not a late arrival caught in the act.

To refuse #1 as it was actually recorded, N would need to be about 118 samples
(790 ms). That exceeds the 0.6 s wind-up plus the 0.1 s `SCHEDULE_MARGIN_S` that
Layer A reserves (`hardware_config.h:492`, `StateMachine.cpp:768-771`), so it would
refuse throws systematically rather than catch a rare late arrival. Not recommended,
and not done. What FW 5 does still catch of throw #1's shape is any check instant
earlier than about t = -0.705 s, i.e. while it was genuinely converging or within
100 ms of band entry.

**The trade the design carries.** The brief's design (N = 15 at 150 Hz = 100 ms,
`YAW_RATE_TOL_DPS` 3.0 to 12.0) was implemented as specified, with no constant
changed from what was asked. It carries a trade-off worth stating plainly rather than
leaving inside a constant: by the convention of holding the rate for the whole 0.6 s
wind-up, the rate term's worst-case aim-budget ceiling at 1.1 m is 4x FW 4's (see the
table in Fix). Read alone, that overstates the real exposure, because holding 12 deg/s
for the full wind-up after 100 ms inside tolerance means travelling 7.2 deg past the
target against a live P loop, which is a controller failure, not a throw the gate is
meant to admit. The history term bounds what the rate term can actually pass in
practice: for a monotonic approach that stops at its target, FW 5 passes a moving yaw
only while it is still converging, and only at 8 deg/s or slower with error at or
below 0.23 deg (4.4 mm), tightening to 2 deg/s at 0.80 deg or below. FW 4 passed the
2 to 3 deg/s crawls too, at a looser 0.89 to 0.98 deg. Both statements are true at
once: the nominal ceiling is 4x wider, and the history term makes that ceiling
unreachable for a converging yaw. Recording both here rather than only the reassuring
half is the point of this section.

## Fix

The rule is now two terms, both must hold: (a) error inside 1.0 deg
(`YAW_ERR_TOL_DEG`, unchanged) for the last 15 consecutive 150 Hz control samples
(`YAW_SETTLED_MIN_SAMPLES`, new, 100 ms at 150 Hz), AND (b) filtered rate at or below
12 deg/s (`YAW_RATE_TOL_DPS`, was 3.0), AND the old instantaneous error check (also
inside 1.0 deg, now redundant with (a) but kept). No numeric error tolerance changed;
the rate bound widened and a sample-count history term was added alongside it.

Aim budget at 1.1 m, `1100 * tan`, counting the rate as held for the whole
`WINDUP_DURATION_S` = 0.6 s wind-up (a worst case, not an operating figure, see
Discussion):

| Term | FW <= 4 | FW 5 |
|---|---|---|
| error term (1.0 deg) | 19.2 mm | 19.2 mm (unchanged) |
| rate term alone | 3.0 deg/s -> 1.8 deg -> 34.6 mm | 12 deg/s -> 7.2 deg -> 139.0 mm |
| both terms | 2.8 deg -> 53.8 mm | 8.2 deg -> 158.5 mm |

Implementation: the settle history is counted in `YawAxis::controlISR()`
(`YawAxis.cpp:822-831`), right after `last_err_deg_` is set, before the
enable/deadband branch, so a parked-in-tolerance axis keeps counting; it saturates at
`UINT16_MAX` instead of wrapping, and a NaN error fails the `<=` check and resets it
to 0. `readTelemetry()` copies the new `Telemetry::settled_samples` field inside the
existing `noInterrupts()` block (`YawAxis.cpp:588`). `HandTrajectoryStreamer::arm()`
gains a `yaw_settled_min_samples` parameter defaulting to
`AxisSettleCfg::YAW_SETTLED_MIN_SAMPLES` (`HandTrajectoryStreamer.h:45,50`), so a
caller that leaves it out still gets the history term; a default of 0 would have
turned it off silently. `StateMachine.cpp:1013-1015`'s one `arm()` call passes it
explicitly. The serial abort line gains `settled=%u/%u` (`HandTrajectoryStreamer.h:108,112`).
The stale comment citing "logbook 2026-06-19" is fixed to 2026-06-21
(`BallButlerConfig.h:290`); no 2026-06-19 entry ever existed.

Fail-closed side effects, all intended. No yaw pointer leaves `Telemetry`
value-initialised, so `settled_samples = 0` and the throw refuses. The ISR not
running leaves the count at 0 and refuses. A hard-limit fault now resets the counter
and refuses (`YawAxis.cpp:804`); FW 4 read a placeholder `last_err_deg_ = 0` on that
same path and passed the error term, so a faulted yaw used to be able to pass Layer C.

Struct safety was checked before adding the field: `Telemetry` is only ever read by
field name, never serialised and never positionally initialised (grep of
`ball_butler_main/`: `HandTrajectoryStreamer.h:97` and `ball_butler_main.ino:176,465,480`
are the only readers), so the new field cannot desync a wire layout that does not
exist.

Lockstep with Jugglebot, following the FW 2/3/4 receipt convention: `FwUpdate.h:76,80`
sets `FW_VERSION = 5` with a one-line receipt comment; `teensy_link/rpc_args.py:486-494`
(Jugglebot `skill-stack` worktree) pins `BB_FW_VERSION_EXPECTED = 5` the same way.
There is no wire or protocol change: `THROW_ABORTED_NOT_SETTLED` detail0 (binding
axis) and detail1 (yaw error, centidegrees) keep their meanings, and nothing on the
runtime path compares the firmware version against the constant (only
`tests/firmware/test_bb_fw_update_xref.py:111`, tree vs tree, does). The flash receipt
is the fw-update tool's own `FW version: 4 -> 5` line, not the constant and not a
matching hex md5.

## Outcome

**Build** (2026-09-30, 18:31, `cd ~/Desktop/BallButler/ball_butler_main && pio run -e
teensy40_can`, no `-t upload`): `[SUCCESS] Took 5.04 seconds`, 0 warnings, 0 errors.
`.pio/build/teensy40_can/firmware.hex`: 460937 B, md5 `4798642934b60aaa43edee5b985d3aa1`.

**No BB native or unit tests exist** for `YawAxis` or the streamer: `platformio.ini`
has no native env and `ball_butler_main/test` does not exist. Cross-repo tests
(Jugglebot, `skill-stack` worktree, 2026-09-30): `pytest
tests/firmware/test_bb_fw_update_xref.py -v` gave 5 passed in 0.10 s (5 passed in
0.09 s again after the final comment edit); `pytest tests/firmware -q` at 18:33 gave
263 passed, 1 skipped in 12.42 s. The full `./run_tests.sh` gate was not run as part
of this change.

**Offline gate model** (`python3 scratchpad/probe_bb_fw5_gate.py`, output in
`scratchpad/probe_bb_fw5_gate.out`; mirrors the ISR's count quantisation, EMA and
counter, and the streamer's `yaw_ok`, for FW 4 vs FW 5): probe A confirms FW 4
refuses kicks of 4 or more counts and 2+2, FW 5 passes up to 12 counts and 7+7, and
both refuse 13 counts and 8+8. Probe B confirms FW 5 never passes while moving faster
than 8 deg/s, and on fast arrivals it first passes 93 ms after band entry against
FW 4's 67 to 80 ms, up to 26 ms stricter there. Probe C is the throw #1 replay in
Discussion.

**Flash status: FLASHED 2026-09-30 22:45.** Flashed 2026-09-30 22:45 by Claude over CAN with the worktree's tool (the BB build's `pio` upload hook calls the MAIN checkout's `tools/teensy_link_bridge.py`, which is on `mvp-trajectory-bringup` at protocol 6 and dark against the protocol-9 bridge): `python tools/teensy_link_bridge.py --fw-update .../teensy40_can/firmware.hex --target bb`, a `--verify-only` rehearsal first (DATA 26.3 s, VERIFY OK, COMMIT withheld), then the real run: FW version before 4, BEGIN OK (BB parked, pitch 89.8 deg), DATA 163 840 B in 25.7 s (0 rewinds, 0 window retries, 0 missing acks), VERIFY OK crc32 0xF292D1C1, COMMIT OK, receipt **`Ball Butler FW version: 4 -> 5`** at 22:45:45 (log `Jugglebot-skills/temp/logs/bb_fw5_flash_20260930_2242.log`).
Note for the next flash: `pio run -e teensy40_can -t upload` is NOT safe until
`platformio.ini`'s upload hook is repointed (it names `../../Jugglebot/tools/
teensy_link_bridge.py`, the main checkout, protocol 6); drive the skill-stack worktree's
copy directly as above.

**What to watch at the next sitting.** Count `THROW_ABORTED_NOT_SETTLED` on
`/bb/throw_outcome` against this sitting's baseline of 5/19 (4 on plateaus, 1 on
throw #1's tail); expect close to 0 on plateaus. For any refusal, the BB serial line
now prints `settled=N/15 rate=R`, naming the binding term: N < 15 means the history
term bound it (a real late arrival), R > 12 means the rate term bound it (a
traverse). detail1 is still yaw error in centidegrees, so the Jugglebot decode needs
no change. The dither mechanism itself is still unmeasured at 150 Hz on real
hardware; if a residual refusal rate persists after the flash, capture
`Telemetry.vel_rps` / `vel_rps_raw` over USB serial on the bench around a throw.

## Open Questions / Follow-ups

1. **Flashed and confirmed** (2026-09-30 22:45, receipt `FW version: 4 -> 5`). Open in
   its place: repoint `platformio.ini`'s `upload_command` at a checkout on the bridge's
   protocol (today the skill-stack worktree), since the main checkout's tool is dark.
2. **Layer A follow-up: the 100 ms dwell eats the schedule margin.** The new history
   term's 100 ms dwell inside tolerance is not reserved anywhere in Layer A's lead
   calculation; it eats into the 0.1 s `SCHEDULE_MARGIN_S` Layer A already reserves
   without accounting for it explicitly.
3. **Layer A follow-up: the traverse-rate assumption is roughly 4x optimistic near
   the target.** Throw #1's 17.4 deg move took about 1.2 s to reach the band. Layer A
   assumes `YAW_TRAVERSE_DEG_PER_S = 60`, which predicts 0.29 s. The P plus
   tapered-feedforward approach is roughly 4x slower than Layer A assumes near the
   target; this is a Layer A sizing question, not something this change addresses.
4. **Cross-reference in Jugglebot updated.** `tests/ros/test_skill_node.py:3322` and
   `skill_node.py`'s retry docstring cited `HandTrajectoryStreamer.h:104-110` for the
   abort block; it moved to `:117-122` in this change and both cites were updated on
   the Jugglebot side the same evening (skill-stack worktree).
5. **Mechanism still unmeasured live.** The dither mechanism is inferred from source
   and an offline model built from a 10 Hz bag, not measured at the firmware's own
   150 Hz on hardware. See Outcome for the bench measurement that would close this.

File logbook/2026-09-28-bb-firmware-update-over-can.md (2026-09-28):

---
title: Firmware update over CAN — the Platform receiver ported to Ball Butler, with a safety park
type: feature
date: 2026-09-28
status: in-progress
phase: "BB FW 1 / can-bridge FW 21"
related_entries:
  - 2026-06-23-loud-command-outcome-channel-cmd-result
files_changed:
  - ball_butler_main/FwUpdate.h (new)
  - ball_butler_main/FwUpdate.cpp (new)
  - ball_butler_main/FwUpdate.h (FW_VERSION 1 -> 2 -> 3 -> 4, receipts for each CAN flash)
  - ball_butler_main/FwUpdate.h (FW_VERSION 2 -> 3, receipt for the faster transfer)
  - ball_butler_main/CanInterface.cpp
  - ball_butler_main/BallButlerConfig.h
  - ball_butler_main/ball_butler_main.ino
  - ball_butler_main/platformio.ini
  - ball_butler_main/protocol_config.h (generated)
  - ball_butler_main/hardware_config.h (generated)
external_changes:
  - "Jugglebot: config/protocol_config.yaml (BallButlerCanId FW_UPDATE_CMD 0x7D6 / FW_UPDATE_REPLY 0x7D7)"
  - "Jugglebot: config/generate_udp_protocol.py (RPCs BB_FW_BEGIN/DATA/VERIFY/COMMIT/INFO 0x5B-0x5F)"
  - "Jugglebot: ros_ws/src/jugglebot/Teensy_code_canbridge/{platform_relay,can_buses,rpc,canbridge_config} (CAN1 relay + reply routing, FW 20 -> 21)"
  - "Jugglebot: teensy_link/rpc_args.py (PARKING/PARK_FAILED statuses, FW_OP_INFO, BB_FW_VERSION_EXPECTED)"
  - "Jugglebot: tools/teensy_link_bridge.py (--fw-update --target bb)"
  - "Jugglebot: tests/firmware/test_bb_fw_update_xref.py + native/teensy_link tests"
  - "Jugglebot logbook: 2026-09-28-bb-firmware-over-can-relay"
  - "Jugglebot commits: a229edd, 4ad301b (mvp-trajectory-bringup)"
subsystem:
  - firmware
  - tooling
tags:
  - safety
  - testing
---

# Firmware update over CAN — the Platform receiver ported to Ball Butler, with a safety park

## Summary

Ball Butler can be flashed over CAN through the can-hub:
`pio run -e teensy40_can -t upload` builds the image and hands it to Jugglebot's
`tools/teensy_link_bridge.py --fw-update --target bb`, which streams it through the
can-bridge's new `BB_FW_*` relay (CAN1 0x7D6/0x7D7) into `ball_butler_main/FwUpdate.cpp`.
The receiver is the Platform Teensy's (Jugglebot, flashed Platform FW 6 over CAN on
2026-09-09), ported nearly verbatim. The one real addition is a **park** before any
flash is touched: yaw e-stopped, pitch raised to ≥ 80° if it is lower, then the pitch
and hand ODrives set IDLE. Every session ends in a reboot. **Flown 2026-09-28:** bridge FW 21 and BB FW 1
over USB, a clean `--verify-only`, then **BB FW 2 over CAN (INFO 1 → 2, 75.8 s,
0 rewinds)**. The park's pitch-raise branch is still unexercised (pitch was already
stowed both times).

## Motivation

The owner wanted BB flashable the way the Platform is, re-using that system. Both
boards sit behind the same can-hub Teensy. BB's USB still works, so this adds a
convenient single flash path and USB stays the recovery path.

## Design

**Re-used unchanged:** the wire contract (BEGIN/DATA/VERIFY/COMMIT, 5 B per DATA
frame, ACK every 16th, BAD_SEQ rewind), staging above the running image up to the
0x601F0000 EEPROM-emulation reserve, per-sector read-back (`FLASH_ERR`), CRC-32 +
identity marker at VERIFY, and the low-to-high interrupts-off copy + `SCB_AIRCR`
reset. Same MCU, same core primitives, same linker symbol.

**The park (owner-agreed 2026-09-28).** A sector erase disables interrupts for up to
~400 ms. BB's yaw PID runs in an IntervalTimer ISR, so during an erase the yaw motor
would hold its last PWM with no control loop. The Platform never had this problem
because all its motors are ODrives. So the first BEGIN accepted in IDLE or ERROR
latches a session and parks:
1. `yawAxis.estop()`: PWM latched at 0, which stays safe while the ISR is blocked.
2. If pitch is below `PITCH_MIN_STOW_DEG` (80°): pitch goes CLOSED_LOOP and moves
   to `PITCH_DEG_HOME` (90°). Owner: below ~70° an IDLE pitch drops.
3. Once pitch is ≥ 80° and its trajectory is done (or it is already IDLE): pitch
   and hand ODrives are set IDLE, re-requested every 200 ms until both heartbeats
   report IDLE.

Until parked, BEGIN answers `PARKING` (detail = pitch in signed centidegrees) and the
host re-sends it. The park times out after 10 s → `PARK_FAILED` and a reboot. Pitch
angle and freshness come from the ODrive encoder estimate on the **monotonic** clock
(`axisPVMonoAgeUs`), not Proprioception's wall-clock stamp, which the time-sync
slews. The TOO_BIG capacity check runs *before* the park, so the robot never parks
for an image that cannot fit.

**Every session ends in a reboot (owner's call).** COMMIT reboots into the new image.
An abandoned session (60 s without a command: a `--verify-only` run, a crashed host,
a failed VERIFY) and a failed park reboot too. BB therefore always comes back through
BOOT with every axis freshly initialised, never from a half-restored park, and the
session is a one-way latch. While it is open, `loop()` freezes the state machine
and streamer (`pitch.loop()` keeps running, since the park needs it), CAN
throw/reload/reset/calibrate commands are dropped, and serial commands are ignored.

**Identity.** `FwUpdate::FW_NAME = "ballbutler-main"`, `FW_VERSION = 1`, and a boot
banner line. `INFO` (opcode 0x05) returns `FW_VERSION`. BB had no firmware version
on any wire before this; it is the receipt that a COMMIT landed.

## Implementation

- `FwUpdate.{h,cpp}`: receiver + park; hooked from `CanInterface::handleRx_` (0x7D6,
  before every other dispatch) and `loop()` (`FwUpdate::tick()`); `attach()` first
  thing in `setup()`, so a frame arriving during the boot waits is safe.
- `BallButlerConfig.h`: `CanIds::FW_UPDATE_CMD/REPLY`.
- `platformio.ini`: `[env:teensy40_can]` (custom upload → the tool with `--target bb`)
  and a "FLASH OVER CAN" header section. The `teensy40` USB env is unchanged.
- The generated headers were regenerated from Jugglebot `mvp-trajectory-bringup`.
  This replaced an uncommitted resync from the `skill-stack` worktree
  (`hand_tor = 1000`, no `TRAJ_CMD`), which that worktree's generator reproduces.
  Against `HEAD` the result is behaviour-neutral for BB: `InputScale::hand_tor`
  stays 100, and none of the other changed namespaces are used by BB.

## Verification

- **Build** (`pio run -e teensy40` and `-e teensy40_can`, 2026-09-28): both SUCCESS.
- **Image** (`teensy_link_bridge.py --fw-update .pio/build/teensy40/firmware.hex
  --dry-run --target bb`, 2026-09-28): 163840 B, crc32 `0x7AE1BDEB`, identity OK;
  `--target platform` refuses it (no `jugglebot-platform` marker).
- **Host + relay** (Jugglebot, 2026-09-28): an end-to-end loopback through the real
  RPC client against a simulated BB receiver (PARKING ×2, a lost DATA frame
  recovered by rewind, VERIFY, COMMIT, INFO 1 → 2), 10/10 runs. Native relay tests
  and a cross-repo xref pin this repo's `FwUpdate.cpp` status table, opcodes,
  `FW_NAME` and `FW_VERSION` to the host's. Details and the full-gate line are in
  the Jugglebot entry.
- **Not yet on hardware.** The park sequence, the heartbeat-confirmed IDLE and the
  real transfer are unexercised.

## Addendum 2026-09-28 — flown

Receipts (full detail + logs in the Jugglebot entry's addendum):
- Bridge FW 21 over USB → `BRIDGE_IDENTITY fw_version=21`.
- BB FW 1 over USB (`pio run -e teensy40 -t upload`, md5 `6486f041…`) → `BB_FW_INFO` over
  CAN returned **1**.
- `--verify-only` 11:30: park from IDLE with pitch at 89.9° → axes idled and yaw
  e-stopped at +1.2 s, BEGIN OK (staging `0x60028000..0x601F0000`, 1824 KB free),
  DATA 61.0 s with 0 rewinds, VERIFY OK `0x7AE1BDEB`, then at +60 s "session idle 60 s —
  aborted — rebooting"; BB came back IDLE, hand homed, ball in hand. **The
  reboot-ends-every-session rule behaved as designed.**
- CAN flash 11:34 (`pio run -e teensy40_can -t upload`, FW 1 → 2, no code change):
  VERIFY OK `0x25386A01`, COMMIT OK, **`Ball Butler FW version: 1 -> 2`**, 75.8 s total,
  0 rewinds; console `[boot] ballbutler-main v2`, homing successful, BOOT → IDLE.
- Unexplained, instrument-side: the USB console delivered no `[fwupd]` lines during the
  CAN flash (it did during the rehearsal). The receipts do not depend on it.

## Addendum 2026-09-28 — FW 3: the faster transfer (host-side only)

No firmware code change. FW_VERSION 2 → 3 is the receipt for a host-side speed-up in
Jugglebot's flash tool (detail in its entry's addendum): BB's post-sector pause
went from 0.5 to 0.12 s (a flush is ≈ 52 ms typical; a slow erase falls back on the
BAD_SEQ rewind). `--verify-only` 12:10: DATA 45.9 s, 0 rewinds, VERIFY OK. CAN flash
12:14 (`pio run -e teensy40_can -t upload`): DATA **45.8 s** (was 61.0), 0 rewinds,
VERIFY OK `0x1070D8A7`, **`Ball Butler FW version: 2 -> 3`**, **56.25 s total** (was
75.84). Pipelining the DATA RPCs failed cleanly (aborted before VERIFY): the bridge's
RPC UDP socket queues one packet, so the transfer is bounded at one frame per ~1 ms
bridge tick until a bridge FW raises that queue. BB's USB was not attached this
sitting. The copy/COMMIT path was untouched, so its risk was the FW 2 flash's.

## Addendum 2026-09-28 (afternoon) — FW 4 over CAN in 36 s

Can-bridge FW 22 deepened its RPC socket's receive queue from 1 to 8 (Jugglebot
entry `2026-09-28-bb-firmware-over-can-relay`, afternoon addendum), which let the host
pipeline DATA 4 frames deep. `--verify-only`: DATA 25.3 s, 0 rewinds, VERIFY OK. Then
**FW 4 over CAN** (`pio run -e teensy40_can -t upload`, no code change, the receipt):
DATA 25.3 s, 0 rewinds / retries / missing acks, VERIFY OK `0x9A8BC5D5`, COMMIT OK,
**`3 -> 4`, 36.22 s total**, down from 75.84 s for the first CAN flash. The receiver
firmware is unchanged; only the bridge and host moved.

## Open Questions / Follow-ups

- **Exercise the pitch-raise park:** with BB IDLE, lower pitch below 80° from the USB
  console (the serial pitch command; the IDLE handler then holds it CLOSED_LOOP
  because it is below the stow angle) and run `--verify-only`. A GUI manual aim does
  not work for this: it puts BB in TRACKING, which BEGIN refuses. Expect PARKING polls for a few seconds while pitch rises to 90°,
  then the IDLE confirmation. This is the only park branch not yet seen on hardware.
- The common park is from IDLE, where BB already rests pitch IDLE at ≥ 80°, so it
  only idles the hand. A park from ERROR with a faulted pitch ODrive below 80°
  cannot raise pitch; it answers PARK_FAILED and reboots, and USB is the path then.

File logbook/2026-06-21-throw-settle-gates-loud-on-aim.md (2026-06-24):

---
title: Throw settle-gates — loud + guaranteed-on-aim throws (A predictive / B loud channel / C fire-time confirm)
type: feature
date: 2026-06-21
status: tuned   # Phase 1 (A + C + serial) hardware-validated 2026-06-23; Phase 2 (loud-to-host channel) COMPLETED 2026-06-24 — see 2026-06-23-loud-command-outcome-channel-cmd-result.md
phase: V1 reliability
files_changed:
  - ball_butler_main/StateMachine.cpp
  - ball_butler_main/HandTrajectoryStreamer.h
  - ball_butler_main/PitchAxis.h
  - ball_butler_main/BallButlerConfig.h
  - ball_butler_main/CanInterface.cpp
  - ball_butler_main/CanInterface.h
  - ball_butler_main/scripts/bin/teensy_loader_cli
  - zTesting/throw_testing/validate_settle_gates.py
external_changes: []   # Phase 2 will touch Jugglebot (protocol, can-bridge, teensy_bridge_node, ball_butler_node)
commits:
  - 352bb44   # Phase 1: A + C + serial logging
  - 24e0906   # carry-forward teensy_reboot + 2026-05-24 entry
  - efbd8cc   # teensy_loader_cli wrapper — fixes pio run -t upload (two-device-safe)
  - 6c16b08   # name binding axis in rejects/aborts + err; track-hold validation driver
  - a8b5058   # audit cleanup: strip per-throw diag, Layer-C freshness guard, drop pre-engage
subsystem:
  - firmware
  - throwing
tags:
  - safety
  - timing
  - throw
related_entries:
  - 2026-05-24-bb-axis-settled-gate   # superseded original gate (settle-by-release, in executeThrow_, silent)
---

# Throw settle-gates — loud + guaranteed-on-aim throws

## Summary

BB throws had two failure modes: (1) the hand could fire while pitch/yaw were
still slewing, releasing the ball **off-aim**; and (2) a throw could be
**silently dropped** by firmware checks that run *after* `requestThrow` already
returned "queued" to the host — the ball just never fires, no feedback.

A design review reframed bad throws into three categories:

| Category | Example | Handled before this work? |
|---|---|---|
| **Impossible** (infeasible) | out of reach; pitch/yaw/speed/height beyond limits | ✅ loud, host-side (`solve_throw_local`) |
| **Not-ready** | no ball, no time-sync, PV stale | ⚠️ partly (sync checks loud, `executeThrow_` checks silent) |
| **Un-aimable-in-time** | feasible, but scheduled too soon to slew the platform | ❌ nothing |

The fix is three layers: **A** a predictive *settle-before-wind-up* gate
(fail-fast), **C** a fire-time settled confirm via the encoders (the real
guarantee), and **B** a loud outcome channel back to the host (visibility).
**Phase 1 (this entry) lands A + C + serial-only outcomes, firmware-only.**
Phase 2 builds the reusable host-facing loud channel + a ROS2 action.

## Motivation

"Impossible" throws are already rejected *loudly* host-side: `solve_throw_local`
(Jugglebot `can/throw_ballistics.py`) enforces pitch/yaw/speed/height limits and
raises `ValueError` → `ball_butler_node` returns `success=False` with a message.
The remaining gap is the **un-aimable-in-time** case plus the architectural fact
that the firmware's own rejections live in `executeThrow_`, which runs
asynchronously in `handleIdle_` *after* the host was told "queued" — so they are
invisible. "Loud + on-aim" therefore needs **both** a timing gate and a
feedback channel.

## Design

- **Three layers, one rule.** A predicts the axes will be settled **before the
  hand wind-up begins**; C confirms it with the encoders at the last instant
  before any hand motion; B reports the outcome. They compose: A = fail-fast,
  C = guarantee, B = visibility.
- **Why settle-before-wind-up (not -before-release).** It keeps an *accepted*
  throw trustworthy: A and C share the same rule, so C only ever fires on an A
  *misprediction*. Cost is ~0.6 s more required lead — free at the ~2.5 s
  operating leads, and the cleaner physical model (platform locks on target,
  *then* the hand moves).
- **C uses the direct sensor, not a prediction** (pitch `trajectory_done` + yaw
  error/rate) — the project's "suspect the instrument" principle applied at the
  one moment that matters.
- **Architecture finding that scoped Phase 2.** Host↔BB is three-tier:
  host ⇄ **UDP** ⇄ can-bridge Teensy ⇄ **CAN1** ⇄ BB. The `BB_THROW` RPC acks at
  the *bridge* (frame transmitted), never at BB — the root cause of silent
  throws. A new BB→host result frame must be **explicitly relayed** by the
  bridge, so the loud channel spans the CAN protocol + the UDP protocol + BB
  emit + bridge relay + host action (5 components, not 2).

## Implementation (Phase 1)

- **Layer A** — relocated the predictor (from the superseded 2026-05-24 gate,
  commit `2f9d72b`) into `StateMachine::requestThrow` so the reject is
  **synchronous**, and changed the rule to
  `lead ≥ max(pitch_settle, yaw_settle) + WINDUP_DURATION + SCHEDULE_MARGIN`.
  Closed-form trap-traj pitch estimator (asymmetric accel/decel, reads
  `pitch_.getTraj()`) + constant-rate yaw estimator. `PitchAxis::getTraj()`
  accessor added.
- **Layer C** — one-shot confirm in `HandTrajectoryStreamer::tick()` evaluated
  when frame 0 is due: pitch `trajectory_done` from a **fresh** heartbeat
  (`hb_age < PITCH_HB_FRESH_US`, sync-immune mono age — so a stalled/dropped
  heartbeat can't confirm "settled" on stale data) AND `|yaw_err| < 1.0°` AND
  `|yaw_rate| < 3.0°/s` (from `YawAxis::readTelemetry()`). Not settled → **abort
  with zero frames sent**; ball retained; `handleThrowing_` returns to IDLE (no
  reload). Reads only cached state → **zero added throw latency**.
- **`AxisSettleCfg`** (firmware-local tunables): `YAW_TRAVERSE_DEG_PER_S = 60`,
  `WINDUP_DURATION_S = 0.6`, `YAW_ERR_TOL_DEG = 1.0`, `YAW_RATE_TOL_DPS = 3.0`,
  `PITCH_HB_FRESH_US = 300000`.
- **B-on-serial** — both gates name the binding axis: A prints `[SM] Throw
  rejected: PITCH/YAW can't settle before wind-up …`; C prints `[Gate] Throw
  ABORTED — PITCH/YAW not settled … err=0x…`. (The CAN `THROW_RESULT` message +
  bridge relay + action are Phase 2.)

## Verification

- **Build:** `pio run` passes both `teensy40` / `teensy41`.
- **Hardware — VALIDATED 2026-06-23** (BB serial monitor + `bb/send_throw_command`
  via `validate_settle_gates.py`, with continuous track-hold keeping pitch engaged
  on-aim, as in production):
  1. **ACCEPT, Δ≈0, 2 s lead** → `pitch_state=8 err=0x0` at queue, `settled-confirm
     OK` at fire → **threw**.
  2. **REJECT, Δpitch 50°, 1 s lead** → `Throw rejected: PITCH … need 1992 ms,
     have 1000` → no throw.
  3. **ACCEPT, Δpitch 50°, 3 s lead** → armed, slewed 30→80°, **threw**.
  4. **REJECT, Δyaw 45°, 1 s lead** → `Throw rejected: YAW … need 1397 ms, have
     1000` → no throw.
  All four correct; both ACCEPTs fired, both REJECTs named the binding axis;
  `err=0x0` and heartbeat fresh (~50–100 ms) throughout.
- **Key finding — Layer C works as the safety net.** Earlier runs aborted the
  Δ≈0 throw with `pitch_done=0`. Not a false reject: pitch had genuinely fallen to
  IDLE at the ~90° stow position and was mid-re-engage at fire, because the *test*
  used a single park + 5 s wait that let tracking time out. Diagnostics confirmed
  pitch was truly IDLE (`pitch_state=1`) with a *fresh* heartbeat — not a stale-log
  artifact. The fix was the test driver (continuous track-hold = production
  behaviour), not the gate.
- **Post-validation audit** (`/code-review`, no correctness bugs in the validated
  path): stripped the per-throw diagnostic prints (investigation scaffolding;
  the streamer one was a raw `Serial.printf` on the fire path); added the Layer-C
  heartbeat-freshness guard; removed the `requestThrow` pre-engage (redundant with
  `executeThrow_`'s command, and track-hold — not pre-engage — was the real fix).
- **Fallback (pre-registered):** if A over-rejects throws the hardware would make,
  raise `YAW_TRAVERSE_DEG_PER_S` 60 → 90 and re-flash.

## Open Questions / Follow-ups

- **Phase 2 (DONE — built + hardware-validated 2026-06-24, see
  [2026-06-23-loud-command-outcome-channel-cmd-result.md](2026-06-23-loud-command-outcome-channel-cmd-result.md);
  the design below is what shipped): generic command-outcome channel.** The
  throw is the first of several ops (reload, calibrate, home) that want loud
  feedback, so Phase 2 is a *reusable* mechanism, not throw-specific:
  - one generic `CMD_RESULT` CAN message — `cmd_type` + a **shared base outcome
    enum** (OK / REJECTED / ABORTED / TIMEOUT / BUSY) + per-command extensions +
    2 **generic** detail int16s;
  - **one outstanding goal per `cmd_type`** (no correlation token — throws are
    serialized);
  - one bridge relay path (CAN1 → UDP), modelled on the cone-frame relay;
  - a reusable "command action server" base in `teensy_bridge_node` that
    dispatches the RPC, registers the pending goal by `cmd_type`, and completes
    it from the **serial/UDP RX thread** on `CMD_RESULT`;
  - `teensy_bridge` moves to a `MultiThreadedExecutor` + `ReentrantCallbackGroup`
    so result-waits never stall the 100 Hz telemetry;
  - first consumer: `BallButlerThrowCmd.action` **replacing**
    `bb/send_throw_command`; migrate `ball_butler_node`.
- **Layer A wind-up reserve is a fixed `0.6 s`** (`requestThrow` is pre-plan and
  can't read the trajectory's actual `min_ts`; observed `ready_time ≈ 0.5 s`).
  Conservative/safe today; if a high-speed throw's wind-up exceeds 0.6 s, A
  under-reserves and the reject falls to Layer C (late) instead of A (early) — C
  still backstops. Refine only if it bites.
- **Idle-pitch throws abort at Layer C** — `PITCH_REENGAGE_RESERVE_S` is dormant
  (0), so a throw issued while pitch is power-saved to IDLE (before re-tracking)
  has no lead reserved for re-engagement. Production's continuous tracking keeps
  pitch engaged, so it doesn't bite; size the reserve from a measured re-engage
  latency if it ever does.
- **Validation driver has no programmatic pass/fail** — the gate outcome is
  serial-only (`bb/send_throw_command` only confirms delivery); Phase 2's action
  makes it assertable. It also blocks ~25 s per call if the service is down.

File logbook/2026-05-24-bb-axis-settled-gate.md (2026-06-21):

---
title: Axis-settled lead-time gate in executeThrow_ — reject throws that fire before pitch/yaw reach target
type: bugfix
date: 2026-05-24
status: resolved
related_plan: ""
files_changed:
  # Modified
  - ball_butler_main/StateMachine.cpp
  - ball_butler_main/PitchAxis.h
  - ball_butler_main/BallButlerConfig.h
  # New
  - logbook/README.md
  - logbook/INDEX.md
  - logbook/2026-05-24-bb-axis-settled-gate.md
commits:
  - 2f9d72b  # fix(firmware): reject throws before yaw/pitch reach target (axis-settled gate)
subsystem:
  - firmware
  - state-machine
tags:
  - bugfix
  - timing
  - throw
  - kinematics
---

# Axis-settled lead-time gate in `executeThrow_`

> **Superseded (2026-06-21)** by
> [throw-settle-gates-loud-on-aim](2026-06-21-throw-settle-gates-loud-on-aim.md).
> That work keeps this predictor but (a) relocates it into `requestThrow` so the
> reject is *synchronous/loud*, (b) changes the rule from settle-by-**release** to
> settle-before-**wind-up**, and (c) adds a fire-time encoder confirm (Layer C).
> The symptom/diagnosis/kinematics below remain accurate; the *placement and
> acceptance rule* are what changed. Kept for history.

## Symptom

Operator reported on hardware: *"BB tends to throw very early; the pitch and
yaw axes are still finding their positions by the time the hand throws."*
Every throw with a different aim from the previous one released at the wrong
angle — landing direction non-deterministic.

## Diagnosis

[`StateMachine::executeThrow_`](../ball_butler_main/StateMachine.cpp) (in the
pre-fix version) does, in order:

1. Command yaw + pitch to their targets (motors start moving).
2. Plan the hand trajectory.
3. Check lead time against **only** the hand wind-up.
4. Arm the streamer.

There is no check that yaw + pitch will be at their target by the time the
hand fires the ball. The pitch ODrive runs `trap-traj` configured at
`traj_vel_rps = 1.0`, `traj_accel_rps2 = 0.5`, `traj_decel_rps2 = 0.25` (from
`hardware_config.h`). A 60° pitch change is a triangular profile of ~1.42 s
total; a 30° change ~1.00 s; a 10° change ~0.58 s. Hand wind-up only needs
~600 ms, so any throw scheduled with ~1.0 s lead but a meaningful pitch change
passes the existing lead-time check, the hand fires at +600 ms, and the ball
releases while pitch is still mid-traverse. Yaw (PWM-controlled, custom PID)
has no firmware-side time-to-target either, with the same failure mode.

## Fix

Insert a new **step 4b** in `executeThrow_` (between planning and
arming) that predicts each axis's traverse time at queue time and rejects
the throw if the available lead is shorter than
`max(pitch_settle, yaw_settle) + SCHEDULE_MARGIN`.

Two helpers, both anonymous-namespace free functions in `StateMachine.cpp`:

- **`estimatePitchTraverseTimeUs(current_deg, target_deg, traj)`** — closed-form
  trap-traj kinematics with **asymmetric** accel/decel. Computes
  `v_peak = sqrt(2·Δrev / (1/a_acc + 1/a_dec))`; if `v_peak ≤ v_max` returns
  triangular time `v_peak/a_acc + v_peak/a_dec`, otherwise the trapezoidal
  decomposition `t_acc + d_cruise/v_max + t_dec`. Reads the live `Traj` from
  `PitchAxis::getTraj()` (new one-line accessor) so any runtime
  `setTrajLimits()` change is honoured.

- **`estimateYawTraverseTimeUs(current_deg, target_deg)`** — conservative
  constant rate. `t = |Δdeg| / YAW_TRAVERSE_DEG_PER_S`. The rate lives in a
  new `AxisSettleCfg` namespace in `BallButlerConfig.h`; initial value
  **60 deg/s**, tunable.

Defensive: both estimators return `INFINITY` if their inputs are non-positive,
which causes the gate to reject the throw rather than silently accept.

Rejection log mirrors the existing hand-lead reject style:
```
[SM] Throw rejected: yaw/pitch settle needs N ms, have M ms (pitch=… ms, yaw=… ms)
```

## Discussion

**Why predictive estimation and not "wait until trajectory_done"?** The check
runs at *queue time* (`executeThrow_` is called once when a `THROW_CMD`
arrives, then the streamer is armed against an absolute wall-clock fire
time). There's no opportunity to observe actual settling — the firmware
has to *predict* whether the axes will be settled by `pending_throw_wall_us_`.
A wait-loop would change the streamer-arming contract and is out of scope.

**Why asymmetric trap-traj kinematics?** The original prompt's worked
example assumed symmetric accel = decel = 0.5 and arrived at ~1.6 s for 60°.
The actual config has `decel = 0.25` (half of accel), which lengthens the
profile asymmetrically. Using the symmetric formula would underestimate
the move time and let some marginal throws slip through. The asymmetric
formula adds three lines of code and matches the ODrive's behaviour exactly.

**Why a constant rate for yaw, not an empirical step-size map?** Yaw is
PWM-driven through a custom PID loop in `YawAxis.cpp` — no `v_max`/accel
pair to read like the pitch case. Bench-measuring a polynomial would be
more accurate but is out-of-scope work that the operator can choose to
spend later if 60 deg/s proves too conservative. The constraint from the
prompt was *"lean toward safe-rejection"* — a low (slow) rate means
longer estimated time means harder to satisfy means more rejections,
which is the safer failure mode. Operator can tune the constant up if
it rejects throws the hardware would in fact have made.

**Why `AxisSettleCfg` and not `YawDefaults`?** Every constant in
`YawDefaults` is sourced from `BBYaw::` in the auto-generated
`hardware_config.h`. Adding a non-sourced firmware-local constant there
would break that contract. A separate namespace keeps the codegen
boundary clean and signals "this is firmware-local, edit here, no
Jugglebot-side regen needed".

**Why double-applied `SCHEDULE_MARGIN_S` (once in axis gate, once in hand
gate)?** The two gates check independent conditions — *will the hand be
ready in time?* and *will the platform be aimed in time?* — and each
deserves its own margin against jitter / clock skew / unmodelled effects.
The hand gate's margin protects the streamer arming; the axis gate's
margin protects the geometric aim. Sharing the margin would mean the
worse-case axis (typically pitch) consumes the budget that should
protect the hand, or vice versa.

## Verification

**Compile**: Teensy 4.1 firmware via PlatformIO (operator to flash).
The two helpers are `static`-equivalent (anonymous namespace) and only
add a few hundred bytes of flash. No new public API.

**Hardware acceptance criteria** (operator to run; pipeline:
`ros2 launch jugglebot catching_cone_test.launch.py` then issue throws
via the GUI or `bb/send_throw_command`):

1. **No regression** — TRACK to current pose, fire throw at current
   `(yaw, pitch)` with normal lead time. Expected: `[SM] Throw armed: …`
   with no settle-gate rejection (Δyaw=Δpitch=0 → required = margin =
   100 ms, ≪ typical hand-windup lead of ~600 ms).
2. **Settled gate works** — issue throw with `Δpitch = +60°` and
   `throw_wall_us = now + 1000 ms`. Expected:
   `[SM] Throw rejected: yaw/pitch settle needs ~1515 ms, have ~1000 ms`
   (the breakdown shows `pitch≈1415 ms, yaw≈0 ms`).
3. **Same throw with longer lead** — same `Δpitch = +60°` with
   `throw_wall_us = now + 3000 ms`. Expected: `[SM] Throw armed: …`.
4. **Yaw constant-rate gate** — issue throw with `Δyaw = +90°`,
   `Δpitch = 0`, `lead = 1000 ms`. Expected: rejected with
   `yaw≈1500 ms, pitch≈0 ms` (90/60 s = 1.5 s).
5. **Combined max-wins** —
   (a) `Δpitch = 10°, Δyaw = 80°`, lead = 1000 ms → reject; gate log
       shows yaw dominating (`yaw≈1333 ms > pitch≈577 ms`).
   (b) `Δpitch = 60°, Δyaw = 10°`, lead = 1000 ms → reject; gate log
       shows pitch dominating (`pitch≈1415 ms > yaw≈167 ms`).

If criterion 4 or the yaw side of criterion 5 reject throws that the
operator believes the hardware would in fact have made, raise
`AxisSettleCfg::YAW_TRAVERSE_DEG_PER_S` in `BallButlerConfig.h` (try 90
deg/s next) and re-flash. If criterion 2 *accepts* the throw, lower the
constant or revisit the pitch trap-traj config in
`hardware_config.yaml`.

## Related

- Original prompt and design: [plans/active/bb-firmware-axis-settled-check-prompt.md](../../Jugglebot/plans/active/bb-firmware-axis-settled-check-prompt.md) (in the Jugglebot repo).
- Throw-director and live-integration arc on the Jugglebot side: [Jugglebot/logbook/2026-05-23-throw-director-and-cone-live-integration.md](https://github.com/Project-DeepBlue-Juggling/Jugglebot/blob/refactor/logbook/2026-05-23-throw-director-and-cone-live-integration.md) — the host-side workflow that surfaced this firmware bug.

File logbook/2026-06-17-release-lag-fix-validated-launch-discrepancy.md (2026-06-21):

---
title: Release-lag fix validated on hardware; residual δ is a +3° steeper / +10% hot launch
type: investigation
date: 2026-06-17
status: resolved   # 2026-06-18 — see resolution note below; 2026-06-21 — amended (launch is ~7-8% slow, not hot)
related_entries:
  - 2026-06-11-release-lag-firmware-analysis
  - 2026-06-12-temporal-warmup-drift
files_changed:
  - ball_butler_main/HandPathPlanner.cpp
  - ball_butler_main/platformio.ini            # restored (had been removed from the repo)
  - ball_butler_main/scripts/fix_teensy_size_glibc.py
  - ball_butler_main/scripts/bin/teensy_size
  - zTesting/throw_testing/temporal_accuracy/analyze_velocity_postfix.py
  - zTesting/throw_testing/temporal_accuracy/analyze_velocity_robust.py
  - zTesting/throw_testing/temporal_accuracy/analyze_velocity_ransac.py
  - zTesting/throw_testing/temporal_accuracy/analyze_launch_velocity.py
external_changes:
  - "Jugglebot: Teensy_code_canbridge/time_base.{cpp,h} + CatchingCone_code (clock step-on-jump + freshness fix; see 2026-06-12 entry) — FLASHED to both Teensys"
subsystem:
  - throwing
  - firmware
  - calibration
tags:
  - accuracy
  - ballistics
  - timing
  - mocap
---

# Release-lag fix validated on hardware; residual δ is a +3° steeper / +10% hot launch

> **RESOLVED 2026-06-18** — see
> [2026-06-18-temporal-accuracy-resolved-fractured-solution](2026-06-18-temporal-accuracy-resolved-fractured-solution.md).
> The "+3° steeper / +10% hot launch execution error" conclusion below did **not**
> hold up: it was largely the ~44 ms release latency biasing the mocap launch-velocity
> estimate (vz evaluated before the actual release) plus unreliable geometry fits. The
> hand encoder shows the hand throws at **98–101 % of commanded velocity** at the
> designed release point — execution is ~as-commanded. The true residual is a
> **constant ~44 ms actuator latency**, fixed via `aim_correction` (spatial) + a
> measured release-latency offset (temporal) → **arrival error < 10 ms**. All six open
> questions below were investigated there (kinematic-ID and feedforward root-fixes were
> dead ends; the pragmatic temporal offset won).

> **AMENDED 2026-06-21** — refining *both* this entry's headline and the 06-18 note above.
> A fresh trajectory + hand-encoder re-analysis (chapter
> [01 · V0 Throw Accuracy](chapters/01-v0-throw-accuracy.html), Figures 4–6) finds the launch
> is **~7–8 % slow at the commanded angle** — *neither* "+3° steeper / +10 % hot" (this entry)
> *nor* exactly "execution as-commanded" (06-18). Two anchor-clean facts settle it: (1) the
> mocap arc's **curvature** fixes horizontal launch speed at **vh ≈ 0.93 × commanded**
> (anchor-free — needs no release-time/position assumption) ⇒ narrower arc ⇒ slower
> horizontally; (2) the **hand encoder** shows the hand peaks at **97.7 % of commanded** (a ball
> cannot leave faster than the hand ⇒ **not hot**) and the **barrel angle = commanded** (⇒ **not
> steeper**). The deficit decomposes as ≈2.3 % servo under-track + ≈5.5 % hand→ball (uncalibrated
> spool radius / release transfer). The "+3°/hot" was an artifact of evaluating mocap **vz 44 ms
> before the ball releases** (gravity not yet applied) — only horizontal speed is anchor-free.
> It is compensated end-to-end (`aim_correction` + the 44 ms offset), so it is a **low-priority**
> open item; the root lever is `BBTraj::LINEAR_GAIN_FACTOR` (still 1.0, never calibrated). Tools:
> `plot_launch_geometry.py`, `plot_speed_chain.py`, `plot_0617_chain.py`.

## Summary

The release-lag scheduling defect identified on 2026-06-11 (`HandPathPlanner`
decel-zero double-cancellation) was fixed and flashed to the BB Teensy. With the
clock-sync artifact also resolved (2026-06-12), the systematic arrival delay
dropped from **~140 ms → ~44 ms** and the **measured release lag is now ≈ 0**.
The remaining **~44 ms is entirely flight stretch**: mocap shows the ball launches
**~3.1° steeper and ~10% faster than commanded**, reproduced across two sessions
(n≈28/30 each) and two independent track sources. This is an *execution* error
(actual launch ≠ commanded `v0`), not an IK/model error — the spatial aim-correction
absorbs the position consequence, leaving the flight-time consequence as δ.

## Background

- **2026-06-11** found the root cause of the ~82 ms release lag: `makeThrow()`
  shifts the throw so decel sits at t≈0, so `throwTr.t[i_decel]` ≈ 0; both
  decel-zero planners cached that ≈0 instead of the decel offset *relative to the
  throw's first sample* (= `t2`), scheduling the stroke to *start* at `throw_time`
  so the ball released `t2 ≈ 83 ms` late. Fix was deferred pending the clock work.
- **2026-06-12** found the apparent "warm-up drift" was a clock-sync measurement
  artifact (bridge re-acquisition slew); fixed with step-on-jump + freshness.

## Fix

`ball_butler_main/HandPathPlanner.cpp` — both decel-zero sites now subtract the
throw's first-sample time:

- line 72 (`planThrow`, feeds the buffer `planThrowDecelZero` used by the live
  throw path `StateMachine.cpp:858`):
  `last_decel_time_in_throw_ = throwTr.t[i_decel] - throwTr.t[0];`
- line 288 (streaming `planThrowDecelZero`):
  `const float t_decel_in_throw = throwTr.t[i_decel] - throwTr.t[0];`

**Spatially neutral.** The change shifts only the frame *timestamps* (decel/release
now lands at `throw_time`); the anchor, launch position, direction, and release
velocity are unchanged. So it removes the temporal δ *without* moving the landing
point — the validated aim-correction stays valid. This was confirmed by the data
(position accuracy unchanged; δ dropped by ~the predicted t2).

Flashing note: `platformio.ini` + `scripts/` had been removed from the repo and
`pio run -t upload` is broken on the Jetson (`teensy_reboot`/`teensy_size` are
GLIBC-2.34-linked). Restored the build files from git `d5b74b9`; flashed via
`/home/jetson/bin/teensy_loader_cli` (T4-capable, GLIBC-2.17) + a 134-baud serial
reboot. BB Teensy is a **Teensy 4.0**.

## Verification

Post-fix sessions (2026-06-17, clean clock on both Teensys):

| metric | 15:13 run (n=29) | 14:51 run (n=28) |
|---|---|---|
| arrival error (session JSON) | 41–53 ms, flat | 29–58 ms* |
| **\|v\| meas/cmd** | 1.105 ± 0.009 | 1.109 ± 0.012 |
| **vz** | 1.124 ± 0.008 (hot) | 1.128 ± 0.011 |
| **vh** | 0.929 ± 0.015 (slow) | 0.934 ± 0.016 |
| **launch elevation** | 71.0° → 74.1° (**+3.1°**) | 71.0° → 74.1° (**+3.1°**) |
| measured release lag | −16 ms (≈0) | −16 ms (≈0) |
| flight error | +62 ms | +64 ms |
| fit g_eff / RMS | 9763 / 2.5 mm | 9780 / 2.4 mm |

*the 14:51 run showed a within-session ~20 ms climb (early thermal/transient); the
15:13 run did not.

Method (`analyze_launch_velocity.py`): velocity is never finite-differenced — it is
the slope of a multi-sample fit with the physical shape imposed (known-g parabola
`z + ½gT² = z0 + vz·T` for vertical; constant-velocity line for horizontal). Two
independent track sources cross-validate:
- **Track A** (announcement-matched KF, `source=ball_butler`) over the early-mid
  window [tt+0.1, tt+0.6] is **measurement-driven there** (g_eff_free = 9802 ± 32
  mm/s² vs true 9806; RMS ≈ 2 mm; velocity ≠ the commanded prior), n≈26/30.
- **Track B** (prior-free re-detection, `source=human_throw`, RANSAC) covers the
  few throws where A diverges early; agrees with A to <0.5%.

Robustness notes: **vh ≈ 0.93 is release-height independent** (horizontal v is
constant in vacuum) — vh < 1 alone proves a steeper-than-commanded launch. \|v\|
and vz are extrapolated to the model release plane and carry a ~5%-per-50 mm `z_rel`
systematic, so read the +10–12% as "clearly hot, ~10%"; the sign and cross-session
reproducibility are certain.

## Discussion — where the launch discrepancy comes from

The ballistic model (`throw_ballistics.py:76-78`) assumes the launch velocity
direction is *exactly* the commanded pitch (`vz = speed·sinθ`, `vh = speed·cosθ`)
and magnitude is *exactly* `speed_mps`. The measured launch is a **scale (~1.10) +
rotation (+3.1°)** of the commanded vector — fully consistent with both vz and vh
(scale·cos(θ+Δ)/cosθ = 0.93; scale·sin(θ+Δ)/sinθ = 1.125). Two largely independent
effects:

- **Angle (+3.1°, robust):** the physical barrel points steeper than the commanded
  pitch. The chain is commanded `pitch_deg` → firmware map `rev = (deg−90)/360`
  (`PitchAxis.h:16`, assumes load encoder 1:1 with the barrel, zeroed at true
  vertical) → ODrive → physical barrel. Suspects, in order: (a) pitch encoder
  **zero offset** (homing sets rev=0 at a not-quite-vertical pose → constant
  offset); (b) the **linear map is an approximation** — if pitch is driven through
  a linkage rather than 1:1, the true barrel angle vs encoder is nonlinear and the
  `/360` map is only right at one calibration point (this would make any single
  hardcoded offset *unstable across the workspace*); (c) **dynamic deflection** —
  mechanical flex downstream of the encoder under throw reaction torque (a static
  spirit-level check would miss this).
- **Speed (~+10%, less certain — has the `z_rel` systematic):** the hand delivers
  more linear speed than commanded. `BBTraj::LINEAR_GAIN_FACTOR = 1.0`,
  `HAND_SPOOL_RADIUS_M = 0.0052493` (`hardware_config.h:247-248`). Either the
  effective spool radius is larger than configured (string wrap) or the hand
  ODrive overshoots the commanded velocity feed-forward at release. *Not* a
  uniform-scale (LINEAR_GAIN) issue — that can't produce an angle error, so a gain
  change is the wrong lever and `FACTOR=1.0` is being kept.

Firmware paths examined: `PitchAxis.{h,cpp}` (linear deg↔rev map, trap-traj
position control; throw lead time is ~2.5 s so a pitch-settle race is ruled out as
the cause of a *constant* offset), `StateMachine::executeThrow_`,
`HandPathPlanner` / `Trajectory.h` (release at decel = peak hand speed),
`hardware_config.h` (geometry/gain). The discrepancy is in the
command→physical-execution mapping, not the IK math.

## Open Questions / Follow-ups

1. **Pitch calibration vs the barrel — multi-angle.** Measure physical barrel angle
   (digital spirit level) against the BB_pitch ODrive reading at *several* angles
   (e.g. 40/55/71/85°). Constant Δ ⇒ zero offset (a single correction is stable);
   Δ growing with angle ⇒ scale/linkage error (needs the correct kinematic map, not
   an offset — directly answers the "stable across the workspace" worry).
2. **Static vs dynamic.** Log the BB_pitch encoder *during* a throw (ODrive
   telemetry now exists); compare to the static reading to catch reaction-torque
   deflection the encoder doesn't see.
3. **Barrel direction vs ball direction.** Mocap markers on the barrel → does the
   ball leave *along* the barrel axis, or is there loft at release?
4. **Speed, decoupled from mocap.** Log hand ODrive peak velocity during a throw;
   ball speed = v_peak·π·D. Separates spool-radius error from servo overshoot,
   independent of the mocap `z_rel` systematic.
5. **Workspace sweep.** Run `analyze_launch_velocity.py` across varied pitch/speed
   targets to map whether the angle/speed errors are constant, proportional, or
   pose-dependent — decides offset vs scale vs full model correction.
6. Prefer fixing the root cause over a hardcoded offset (may be unstable across the
   workspace). A temporal-only `predicted_tof` correction is available as a
   pragmatic fallback to reach ±10 ms without re-fitting aim.

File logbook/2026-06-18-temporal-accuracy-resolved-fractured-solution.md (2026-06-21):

---
title: "Temporal accuracy resolved (≈44 ms late → <10 ms): aim-correction for space + a measured release-latency offset for time; kinematic-ID and feedforward root-fixes ruled out"
type: investigation
date: 2026-06-18
status: resolved   # 2026-06-21 — amended (launch is ~7-8% slow at the commanded angle; "as-commanded" is the hand, not the ball); see top banner
phase: "V0 throw accuracy — temporal validation"
related_entries:
  - 2026-06-17-release-lag-fix-validated-launch-discrepancy
  - 2026-06-12-temporal-warmup-drift
  - 2026-06-11-release-lag-firmware-analysis
  - 2026-06-10-throw-aim-correction-validated
  - 2026-06-10-temporal-accuracy-protocol
files_changed:
  - ball_butler_main/Trajectory.h               # feedforward sweep — reverted to optimal baseline + documented
  - ball_butler_main/StateMachine.cpp           # monotonic PV-freshness gate; firmware lead-comp tried then reverted
  - ball_butler_main/CanInterface.cpp           # monotonic (sync-immune) PV timestamp + axisPVMonoAgeUs()
  - ball_butler_main/CanInterface.h
  - ball_butler_main/ball_butler_main.ino       # per-axis PV-age / ODrive-state diagnostics in `status`
  - ball_butler_main/hardware_config.h          # regenerated
  - zTesting/throw_testing/temporal_accuracy/    # NEW: kinematic-ID + lag-characterization tooling
external_changes:
  - "Jugglebot: ros_ws/src/jugglebot/jugglebot/ball_butler_node.py — release-latency offset (command the throw BB_OP_THROW_RELEASE_LATENCY_MS earlier)"
  - "Jugglebot: ros_ws/src/jugglebot/jugglebot/can/throw_ballistics.py — bb_release_state() unified forward model; predict_throw now launches from the release point (forward/inverse consistency) + round-trip test"
  - "Jugglebot: config/hardware_config.yaml — BB_OP_THROW_RELEASE_LATENCY_MS=44 (replaces the dead landing_time_offset_ms=-120 relic); BB_AXIS_ESTIMATES 0x86 stream"
  - "Jugglebot: ros_ws/src/jugglebot/launch/jugglebot_launch.py — aim_correction defaults true; rosbag + teensy_bridge_node added"
  - "Jugglebot: ros_ws/src/jugglebot/jugglebot/teensy_bridge_node.py — BB axis-estimate uplink + startup-race fix"
subsystem:
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

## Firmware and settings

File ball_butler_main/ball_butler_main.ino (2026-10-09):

/*
 * ball_butler_main.ino - Main sketch for Ball Butler robot
 * 
 * ARCHITECTURE:
 *   - StateMachine: Orchestrates robot behavior (BOOT -> IDLE -> THROWING -> RELOADING)
 *   - Proprioception: Central repository for axis state data
 *   - CanInterface: CAN communication with ODrives
 *   - YawAxis: Brushed DC motor control
 *   - PitchAxis: ODrive position control
 *   - HandPathPlanner + HandTrajectoryStreamer: Throw trajectory execution
 */

#include "YawAxis.h"
#include "PitchAxis.h"
#include "HandPathPlanner.h"
#include "BallButlerConfig.h"
#include "CanInterface.h"
#include "HandTrajectoryStreamer.h"
#include "Trajectory.h"
#include "Proprioception.h"
#include "StateMachine.h"
#include "FwUpdate.h"
#include <stdarg.h>

// ============================================================================
// GLOBAL OBJECTS
// ============================================================================
CanInterface           canif;
HandPathPlanner        planner;
HandTrajectoryStreamer streamer(canif);
PitchAxis              pitch(canif, NodeId::BB_PITCH);

YawAxis yawAxis(Pins::YAW_SPI_CS, Pins::YAW_INA1, Pins::YAW_INA2, Pins::YAW_PWM,
                YawMotor::PWM_DEADZONE_MIN, YawDefaults::PWM_FREQ_HZ);

StateMachine stateMachine(canif, yawAxis, pitch, streamer, planner);

static bool     yaw_stream_on      = false;
static uint32_t yaw_last_stream_ms = 0;

// ============================================================================
// YAW PROPRIOCEPTION CALLBACK (called from ISR)
// ============================================================================
void yawProprioceptionCallback(float pos_deg, float vel_rps, uint64_t ts_us) {
  // Velocity is kept for the YAW_ESTIMATE CAN frame (0x7D8, CanInterface::
  // maybePublishYawEstimate_) — the stamped 100 Hz yaw on /bb/axis_estimates.
  PRO.setYawPV(pos_deg, vel_rps, ts_us);
}

// ============================================================================
// HELPER FUNCTIONS
// ============================================================================
// ============================================================================
// FORWARD DECLARATIONS
// ============================================================================
void yawPrintHelp();
void yawHandleLine(const char* yawLine);
void pitchHandleLine(const char* line);
void routeCommand(const char* rawLine);
void printTopHelp();
void printStatus();
bool handleThrowCmd(const char* line);
bool handleSmoothCmd(const char* line);

// ============================================================================
// SETUP
// ============================================================================
void setup() {
  // First, so a firmware-update frame arriving during the boot waits below is
  // handled rather than dereferencing unattached hardware.
  FwUpdate::attach(canif, pitch, yawAxis, stateMachine, streamer);

  Serial.begin(OpCfg::SERIAL_BAUD);
  
  // Wait for Serial, but with a shorter timeout and non-blocking approach
  // This prevents hanging if USB is connected but no terminal is open
  uint32_t serialWaitStart = millis();
  while (!Serial && (millis() - serialWaitStart < OpCfg::SERIAL_WAIT_MS)) {
    // Yield to USB stack
    delay(10);
  }
  
  // Additional check: if Serial says it's ready but buffer is full, 
  // we might still block. Give it a moment to stabilize.
  delay(100);
  
  // Only print startup banner if Serial is actually ready
  if (Serial && Serial.availableForWrite() > 64) {
    Serial.println(F("\n========================================"));
    Serial.println(F("       Ball Butler - Starting Up"));
    Serial.println(F("========================================\n"));
    Serial.printf("[boot] %s v%u\n", FwUpdate::FW_NAME, (unsigned)FwUpdate::FW_VERSION);
  }

  Proprioception::setDebugStream(&Serial, false);

  canif.begin(CanCfg::BAUD_RATE);
  canif.setDebugStream(&Serial);
  canif.setDebugFlags(false, false); // timesync | CAN interface — both default OFF.
                                     // To enable the TimeSync stats log, set the first arg true
                                     // (recompile); it then prints at <=0.5 Hz (sync_stats_print_ms).
  canif.setHandAxisNode(NodeId::BB_HAND);
  canif.setPitchAxisNode(NodeId::BB_PITCH);
  canif.setAutoClearBrakeResistor(true, CanCfg::AUTO_CLEAR_BRAKE_MS);
  canif.requireHomeOnlyFor(NodeId::BB_HAND);

  // Add a short delay to give ODrives time to boot and respond to pings
  uint32_t now = millis();
  while (millis() - now < OpCfg::ODRIVE_BOOT_MS) {
    canif.loop();
    delay(20);
  }

  yawAxis.begin();
  // Configure yaw axis with safe initial settings before StateMachine takes over
  // This prevents any erroneous movement during the boot phase
  // The offset places user 0° at encoder 5°, giving headroom for overshoot
  // Limits are set wide initially; StateMachine will tighten them after homing
  yawAxis.setZeroOffset(YawDefaults::BOOT_ZERO_OFFSET_DEG);
  yawAxis.setSoftLimitsDeg(YawDefaults::BOOT_SOFT_LIM_MIN_DEG, YawDefaults::BOOT_SOFT_LIM_MAX_DEG);
  yawAxis.setHardLimitOvershoot(YawDefaults::BOOT_HARD_LIMIT_OVERSHOOT);
  yawAxis.setProprioceptionCallback(yawProprioceptionCallback);

  pitch.begin();

  // StateMachine::Config defaults come from BallButlerConfig.h (SMDefaults::)
  // Only override here if this specific robot needs different values.
  stateMachine.setConfig(StateMachine::Config{});
  stateMachine.setDebugStream(&Serial);
  stateMachine.setDebugEnabled(true);
  stateMachine.begin();

  // Connect state machine to CAN interface for heartbeat publishing
  canif.setStateMachine(&stateMachine);

  Serial.println(F("\nType 'help' for commands.\n"));
}

// ============================================================================
// LOOP
// ============================================================================
void loop() {
  canif.loop();
  pitch.loop();        // keeps running in a firmware-update session: the park raises pitch
  FwUpdate::tick();    // park progression + abandoned-session reboot
  Proprioception::flushDebug();
  if (!FwUpdate::sessionOpen()) {
    // Frozen while a firmware-update session is open (FwUpdate.h): the robot is
    // parked, and every session ends in a reboot, so nothing here resumes.
    streamer.tick();
    stateMachine.update();
  }

  static char serialBuf[128];
  static uint8_t serialLen = 0;
  while (Serial.available()) {
    char c = (char)Serial.read();
    if (c == '\n' || c == '\r') {
      if (serialLen > 0) {
        serialBuf[serialLen] = '\0';
        if (FwUpdate::sessionOpen()) {
          Serial.println(F("[fwupd] session open — serial commands ignored until the reboot"));
        } else {
          routeCommand(serialBuf);
        }
      }
      serialLen = 0;
    } else if (serialLen < sizeof(serialBuf) - 1) {
      serialBuf[serialLen++] = c;
    }
    // else: overflow — silently drop
  }

  if (yaw_stream_on && (millis() - yaw_last_stream_ms >= OpCfg::YAW_TELEM_MS)) {
    yaw_last_stream_ms = millis();
    auto t = yawAxis.readTelemetry();
    Serial.printf("YAW | pos=%.2f cmd=%.2f err=%.2f pwm=%d en=%d\n",
                  t.pos_deg, t.cmd_deg, t.err_deg, (int)t.pwm, t.enabled);
  }
}

// ============================================================================
// COMMAND ROUTING
// ============================================================================
void routeCommand(const char* rawLine) {
  // Make a mutable lowercase copy for case-insensitive matching
  char lc[128];
  strncpy(lc, rawLine, sizeof(lc) - 1);
  lc[sizeof(lc) - 1] = '\0';
  // Trim leading/trailing whitespace
  char* s = lc;
  while (*s == ' ' || *s == '\t') s++;
  char* end = s + strlen(s) - 1;
  while (end > s && (*end == ' ' || *end == '\t')) { *end = '\0'; end--; }
  if (*s == '\0') return;
  // Lowercase in-place
  for (char* p = s; *p; p++) *p = tolower(*p);

  // Calculate offset of trimmed start from rawLine for preserving original case
  const size_t trim_offset = (size_t)(s - lc);
  const char* line = rawLine + trim_offset;  // original-case trimmed version

  if (strcmp(s, "status") == 0) { printStatus(); return; }
  if (strcmp(s, "reset") == 0)  { stateMachine.reset(); return; }
  if (strcmp(s, "ball") == 0)   { Serial.printf("Ball in hand: %s\n", canif.isBallInHand() ? "YES" : "NO"); return; }
  if (strcmp(s, "reload") == 0) { stateMachine.requestCheckBall(); return; }
  if (strncmp(s, "throw ", 6) == 0)  { handleThrowCmd(line); return; }
  if (strncmp(s, "smooth ", 7) == 0) { handleSmoothCmd(line); return; }
  if (strcmp(s, "help") == 0 || strcmp(s, "h") == 0) { printTopHelp(); return; }
  if (strncmp(s, "p ", 2) == 0)     { pitchHandleLine(line + 2); return; }
  if (strncmp(s, "pitch ", 6) == 0) { pitchHandleLine(line + 6); return; }
  if (strncmp(s, "y ", 2) == 0)     { yawHandleLine(line + 2); return; }
  if (strncmp(s, "yaw ", 4) == 0)   { yawHandleLine(line + 4); return; }

  Serial.println(F("Unknown command. Type 'help'."));
}

void printTopHelp() {
  Serial.println(F(
    "\n=== Ball Butler Commands ===\n"
    "  status              : Show state and proprioception\n"
    "  reset               : Reset from ERROR state\n"
    "  throw <vel> <in_s>  : Throw at velocity\n"
    "  reload              : Trigger a reload\n"
    "  smooth <pos_rev>    : Smooth-move hand\n"
    "  p <deg>             : Pitch to angle\n"
    "  y help              : Show yaw commands\n"
  ));
}

void printStatus() {
  Serial.println(F("\n=== Status ==="));
  Serial.printf("State: %s", robotStateToString(stateMachine.getState()));
  if (stateMachine.isError()) Serial.printf(" - %s", stateMachine.getErrorMessage());
  Serial.println();
  Serial.printf("Ball: %s\n", canif.isBallInHand() ? "YES" : "NO");
  
  ProprioceptionData d;
  PRO.snapshot(d);
  Serial.printf("Yaw: %.1f  Pitch: %.1f  Hand: %.3f rev\n",
                d.yaw_deg, d.pitch_deg, d.hand_pos_rev);
  Serial.printf("Hand homed: %s  Streamer: %s  TimeSync: %s\n",
                canif.isAxisHomed(NodeId::BB_HAND) ? "YES" : "NO",
                streamer.isActive() ? "ACTIVE" : "idle",
                canif.hasTimeSync() ? "YES" : "NO");
  // Per-axis PV freshness + ODrive state — diagnose 'PV stale' throw rejects.
  // state: 1=IDLE, 8=CLOSED_LOOP. PV age is ms since the last encoder estimate;
  // it must be < 20 ms (PV_FRESHNESS_US) at throw time or the throw is rejected.
  // If hand PV age is large while pitch is small, the hand ODrive's cyclic
  // encoder broadcast isn't reaching the Teensy (check its CAN msg-rate config).
  const uint64_t now_us = canif.wallTimeUs();
  const uint8_t diag_nodes[2] = { NodeId::BB_PITCH, NodeId::BB_HAND };
  const char* diag_names[2]   = { "pitch", "hand " };
  for (int i = 0; i < 2; ++i) {
    float dp = 0, dv = 0; uint64_t tw = 0;
    const bool pv_ok = canif.getAxisPV(diag_nodes[i], dp, dv, tw);
    CanInterface::AxisHeartbeat hb;
    const bool hb_ok = canif.getAxisHeartbeat(diag_nodes[i], hb);
    const long wall_age_ms = pv_ok ? (long)(((int64_t)now_us - (int64_t)tw) / 1000) : -1;
    const uint64_t mono_age = canif.axisPVMonoAgeUs(diag_nodes[i]);
    const long mono_age_ms = (mono_age == UINT64_MAX) ? -1 : (long)(mono_age / 1000);
    Serial.printf("  %s (node %u): PV=%s mono_age=%ld ms wall_age=%ld ms  state=%u  pos=%.3f vel=%.3f\n",
                  diag_names[i], (unsigned)diag_nodes[i],
                  pv_ok ? "ok" : "INVALID", mono_age_ms, wall_age_ms,
                  hb_ok ? (unsigned)hb.axis_state : 99u, (double)dp, (double)dv);
  }
}

bool handleThrowCmd(const char* line) {
  float vel = 0, in_s = 0;
  if (sscanf(line + 6, "%f %f", &vel, &in_s) != 2) {
    Serial.println(F("Usage: throw <vel> <in_s>"));
    return false;
  }
  if (vel <= OpCfg::THROW_VEL_MIN_MPS || vel > OpCfg::THROW_VEL_MAX_MPS) {
    Serial.printf("THROW: velocity out of range\n");
    return true;
  }
  // Convert relative time to absolute wall-clock time
  const uint64_t throw_wall_us = canif.wallTimeUs() + (uint64_t)(in_s * 1e6f);
  float yaw_deg = PRO.getYawDeg();
  float pitch_deg = PRO.getPitchDeg();
  if (stateMachine.requestThrow(yaw_deg, pitch_deg, vel, throw_wall_us)) {
    Serial.printf("THROW: Queued %.3f m/s in %.3f s\n", vel, in_s);
  } else {
    Serial.printf("THROW: REJECTED (state: %s)\n", robotStateToString(stateMachine.getState()));
  }
  return true;
}

bool handleSmoothCmd(const char* line) {
  float target = 0;
  if (sscanf(line + 7, "%f", &target) != 1) {
    Serial.println(F("Usage: smooth <pos_rev>"));
    return false;
  }
  if (target < 0 || target > TrajCfg::HAND_MAX_SMOOTH_POS) {
    Serial.printf("SMOOTH: out of range [0, %.2f]\n", TrajCfg::HAND_MAX_SMOOTH_POS);
    return true;
  }
  bool ok = stateMachine.requestSmoothMove(target);
  Serial.printf("SMOOTH to %.2f: %s\n", target, ok ? "OK" : "FAIL");
  return true;
}

// ============================================================================
// YAW COMMAND HANDLER
// ============================================================================
void yawPrintHelp() {
  Serial.println(F(
    "\n=== YAW Commands ===\n"
    "Motion:\n"
    "  p <deg>           : Go to position (degrees)\n"
    "  m <deg>           : Move relative (degrees)\n"
    "  d                 : E-stop (disable)\n"
    "  c                 : Clear e-stop\n"
    "\n"
    "Zero Position:\n"
    "  zero              : Set current position as 0 deg\n"
    "  offset <deg>      : Set zero offset directly\n"
    "\n"
    "Limits:\n"
    "  lim <min> <max>   : Set soft limits (degrees)\n"
    "\n"
    "Tuning:\n"
    "  gains <kp> <ki> <kd> : Set PID gains\n"
    "  accel <a> <d>     : Set accel/decel (PWM/s)\n"
    "  ff <pwm>          : Set friction feedforward\n"
    "\n"
    "Status:\n"
    "  s                 : Show status\n"
    "  t                 : Toggle telemetry stream\n"
    "  full              : Show full config\n"
  ));
}

void yawHandleLine(const char* yawLine) {
  if (!yawLine || !yawLine[0]) return;

  // Make a lowercase copy for case-insensitive matching
  char lc[128];
  strncpy(lc, yawLine, sizeof(lc) - 1);
  lc[sizeof(lc) - 1] = '\0';
  // Trim leading whitespace
  char* s = lc;
  while (*s == ' ' || *s == '\t') s++;
  if (*s == '\0') return;
  // Trim trailing whitespace
  char* end = s + strlen(s) - 1;
  while (end > s && (*end == ' ' || *end == '\t')) { *end = '\0'; end--; }
  // Lowercase in-place
  for (char* p = s; *p; p++) *p = tolower(*p);

  // Pointer into original-case line at same offset
  const char* line = yawLine + (size_t)(s - lc);

  // Help
  if (strcmp(s, "help") == 0 || strcmp(s, "h") == 0) {
    yawPrintHelp();
    return;
  }

  // Position command: p<deg> or p <deg> (P3-7: collapsed to single path)
  if (s[0] == 'p' && strlen(s) > 1) {
    int offset = (s[1] == ' ') ? 2 : 1;
    float deg = atof(line + offset);
    if (yawAxis.setTargetDeg(deg)) {
      Serial.printf("YAW: Target -> %.2f deg\n", deg);
    } else {
      Serial.printf("YAW: Target %.2f deg out of limits\n", deg);
    }
    return;
  }

  // Relative move: m <deg> or m<deg>
  if (s[0] == 'm' && strlen(s) > 1 && (s[1] == ' ' || isdigit(s[1]) || s[1] == '-')) {
    float deg = atof(line + 1);
    if (yawAxis.moveRelDeg(deg)) {
      Serial.printf("YAW: Move relative -> %.2f deg\n", deg);
    } else {
      Serial.printf("YAW: Relative move %.2f deg out of limits\n", deg);
    }
    return;
  }

  // E-stop
  if (strcmp(s, "d") == 0) {
    yawAxis.estop();
    Serial.println(F("YAW: E-STOP engaged"));
    return;
  }

  // Clear e-stop
  if (strcmp(s, "c") == 0) {
    yawAxis.clearEstop();
    Serial.println(F("YAW: E-stop cleared"));
    return;
  }

  // Set zero here
  if (strcmp(s, "zero") == 0) {
    yawAxis.setZeroHere();
    Serial.printf("YAW: Zero set at current position (offset=%.2f)\n", yawAxis.getZeroOffset());
    return;
  }

  // Set zero offset directly: offset <deg>
  if (strncmp(s, "offset ", 7) == 0) {
    float offset = atof(line + 7);
    yawAxis.setZeroOffset(offset);
    Serial.printf("YAW: Zero offset -> %.2f deg\n", offset);
    return;
  }

  // Set soft limits: lim <min> <max>
  if (strncmp(s, "lim ", 4) == 0) {
    float minDeg = 0, maxDeg = 0;
    if (sscanf(line + 4, "%f %f", &minDeg, &maxDeg) == 2) {
      yawAxis.setSoftLimitsDeg(minDeg, maxDeg);
      float actualMin, actualMax;
      yawAxis.getSoftLimitsDeg(actualMin, actualMax);
      Serial.printf("YAW: Limits -> [%.1f, %.1f] deg\n", actualMin, actualMax);
    } else {
      Serial.println(F("YAW: Usage: lim <min> <max>"));
    }
    return;
  }

  // Set PID gains: gains <kp> <ki> <kd>
  if (strncmp(s, "gains ", 6) == 0) {
    float kp = 0, ki = 0, kd = 0;
    if (sscanf(line + 6, "%f %f %f", &kp, &ki, &kd) == 3) {
      yawAxis.setGains(kp, ki, kd);
      Serial.printf("YAW: Gains -> Kp=%.2f Ki=%.2f Kd=%.2f\n", kp, ki, kd);
    } else {
      Serial.println(F("YAW: Usage: gains <kp> <ki> <kd>"));
    }
    return;
  }

  // Set acceleration: accel <accel> <decel>
  if (strncmp(s, "accel ", 6) == 0) {
    float accel = 0, decel = 0;
    int n = sscanf(line + 6, "%f %f", &accel, &decel);
    if (n >= 1) {
      if (n == 1) decel = accel;
      yawAxis.setAccel(accel, decel);
      Serial.printf("YAW: Accel -> %.1f / Decel -> %.1f PWM/s\n", accel, decel);
    } else {
      Serial.println(F("YAW: Usage: accel <accel> [<decel>]"));
    }
    return;
  }

  // Set friction feedforward: ff <pwm>
  if (strncmp(s, "ff ", 3) == 0) {
    float ff = atof(line + 3);
    yawAxis.setFF(ff);
    Serial.printf("YAW: Friction FF -> %.1f PWM\n", ff);
    return;
  }

  // Status (brief)
  if (strcmp(s, "s") == 0) {
    auto t = yawAxis.readTelemetry();
    Serial.printf("YAW | pos=%.2f cmd=%.2f err=%.2f pwm=%d en=%d estop=%d\n",
                  t.pos_deg, t.cmd_deg, t.err_deg, (int)t.pwm, t.enabled, t.estop);
    return;
  }

  // Toggle telemetry stream
  if (strcmp(s, "t") == 0) {
    yaw_stream_on = !yaw_stream_on;
    Serial.printf("YAW: Telemetry stream %s\n", yaw_stream_on ? "ON" : "OFF");
    return;
  }

  // Full configuration dump
  if (strcmp(s, "full") == 0) {
    auto t = yawAxis.readTelemetry();
    Serial.println(F("\n=== YAW Full Configuration ==="));
    Serial.printf("Position:     %.2f deg (cmd: %.2f, err: %.2f)\n", t.pos_deg, t.cmd_deg, t.err_deg);
    Serial.printf("Velocity:     %.3f rev/s\n", t.vel_rps);
    Serial.printf("PWM:          %d (u=%.1f, u_slew=%.1f)\n", t.pwm, t.u, t.u_slew);
    Serial.printf("Enabled:      %s\n", t.enabled ? "YES" : "NO");
    Serial.printf("E-Stop:       %s\n", t.estop ? "YES" : "NO");
    Serial.printf("Zero Offset:  %.2f deg\n", t.zero_offset_deg);
    Serial.printf("Limits:       [%.1f, %.1f] deg\n", t.lim_min_deg, t.lim_max_deg);
    Serial.printf("PID Gains:    Kp=%.2f Ki=%.2f Kd=%.2f\n", t.kp, t.ki, t.kd);
    Serial.printf("Accel/Decel:  %.1f / %.1f PWM/s\n", t.accelPPS, t.decelPPS);
    Serial.printf("Encoder:      raw=%u\n", t.raw);
    Serial.println();
    return;
  }

  Serial.println(F("YAW: Unknown command. Type 'y help'"));
}

void pitchHandleLine(const char* line) {
  if (!line || !line[0]) { Serial.println(F("PITCH: type 'p help'")); return; }

  // Trim leading whitespace
  while (*line == ' ' || *line == '\t') line++;
  if (*line == '\0') { Serial.println(F("PITCH: type 'p help'")); return; }

  if (strncasecmp(line, "help", 4) == 0) {
    Serial.println(F("PITCH: <deg> | status | range"));
    return;
  }
  if (strncasecmp(line, "status", 6) == 0) { pitch.printStatusOnce(); return; }
  if (strncasecmp(line, "range", 5) == 0) {
    Serial.printf("PITCH: %.1f .. %.1f deg\n", PitchAxis::DEG_MIN, PitchAxis::DEG_MAX);
    return;
  }
  float deg = atof(line);
  if (isfinite(deg)) pitch.setTargetDeg(deg);
}

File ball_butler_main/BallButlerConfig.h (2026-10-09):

#pragma once
/**
 * BallButlerConfig.h - Centralised hardware & firmware configuration
 *
 * Single source of truth for all values that change with hardware revisions,
 * motor swaps, mechanical dimensions, tuning, or firmware configuration.
 * ODrive protocol constants (command opcodes, control-mode enums, etc.) are
 * NOT included here — they live in the modules that use them.
 *
 * SECTIONS
 *   1.  ODrive Axis States       (protocol, unlikely to change)
 *   2.  CAN Node IDs
 *   3.  Hardware Pins
 *   4.  CAN Bus Configuration
 *   5.  Ball Butler CAN Protocol IDs
 *   6.  Yaw Axis Defaults
 *   7.  Pitch Axis Defaults
 *   8.  Hand Axis / Homing Defaults
 *   9.  Trajectory & Physics
 *   10. State Machine Defaults
 *   11. Ball Detection Configuration
 *   12. Operational Constants
 *   13. Heartbeat Encoding
 */

#include <cstdint>
#include <cmath>

// Shared protocol constants (auto-generated from config/protocol_config.yaml)
#include "protocol_config.h"

// Hardware & geometry constants (auto-generated from config/hardware_config.yaml)
// All namespace aliases below source values from the generated BB* namespaces
// so that YAML changes propagate automatically.
#include "hardware_config.h"

// ============================================================================
// 1. ODrive Axis States
//    Provided by protocol_config.h (namespace ODriveState)
// ============================================================================

// ============================================================================
// 2. CAN Node IDs
//    Provided by protocol_config.h (namespace NodeId).
//    Use NodeId::BB_PITCH and NodeId::BB_HAND directly.
// ============================================================================

// ============================================================================
// 3. Hardware Pins — sourced from hardware_config.h (BBPins)
// ============================================================================
namespace Pins {
  constexpr uint8_t YAW_SPI_CS = BBPins::YAW_SPI_CS;  // AS5047P absolute encoder SPI chip select
  constexpr uint8_t YAW_INA1   = BBPins::YAW_INA1;    // H-bridge direction pin INA1
  constexpr uint8_t YAW_INA2   = BBPins::YAW_INA2;    // H-bridge direction pin INA2
  constexpr uint8_t YAW_PWM    = BBPins::YAW_PWM;     // H-bridge PWM speed pin
}

namespace YawMotor {
  constexpr uint8_t PWM_DEADZONE_MIN = BBYaw::PWM_DEADZONE_MIN;
}

// ============================================================================
// 4. CAN Bus Configuration — sourced from hardware_config.h (BBCan)
// ============================================================================
namespace CanCfg {
  constexpr uint32_t BAUD_RATE              = CanBus::BAUD_RATE;               // from protocol_config.h
  constexpr uint32_t HEARTBEAT_RATE_MS      = BBCan::HEARTBEAT_RATE_MS;
  constexpr uint32_t AUTO_CLEAR_BRAKE_MS    = BBCan::AUTO_CLEAR_BRAKE_MS;
  constexpr uint8_t  MAX_NODES              = BBCan::MAX_NODES;
  constexpr uint32_t SYNC_STATS_PRINT_US    = BBCan::SYNC_STATS_PRINT_MS * 1000u;  // YAML stores ms, convert to µs
}

// ============================================================================
// 5. Ball Butler CAN Protocol IDs
//    Canonical values now in protocol_config.h (BallButlerCanId, PlatformCanId).
//    Local aliases preserve existing call-site names.
// ============================================================================
namespace CanIds {
  constexpr uint32_t HOST_THROW_CMD    = BallButlerCanId::THROW_CMD;
  constexpr uint32_t HEARTBEAT_CMD     = BallButlerCanId::HEARTBEAT;
  constexpr uint32_t RELOAD_CMD        = BallButlerCanId::RELOAD_CMD;
  constexpr uint32_t RESET_CMD         = BallButlerCanId::RESET_CMD;
  constexpr uint32_t CALIBRATE_LOC_CMD = BallButlerCanId::CALIBRATE_LOC_CMD;
  constexpr uint32_t CMD_RESULT        = BallButlerCanId::CMD_RESULT;
  constexpr uint32_t TIME_SYNC_CMD     = SharedCanId::TIME_SYNC;
  constexpr uint32_t FW_UPDATE_CMD     = BallButlerCanId::FW_UPDATE_CMD;    // host → BB (FwUpdate.h)
  constexpr uint32_t FW_UPDATE_REPLY   = BallButlerCanId::FW_UPDATE_REPLY;  // BB → host
  constexpr uint32_t YAW_ESTIMATE      = BallButlerCanId::YAW_ESTIMATE;     // BB → bridge, stamped yaw @150 Hz
}
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

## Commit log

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2026-05-27 Docs: distinguish Ball Butler V0 from V1+
    Make explicit that the operational thrower is V0 — a deliberately
    simple, fixed-base, 3 DoF machine (slip-ring yaw, ~90° pitch, fast
    linear axis, bumper-fed hopper) — and that V1+ on the rover is a
    much larger system. Adds a V0 vs V1+ comparison table and notes
    that no version of Ball Butler catches balls. Also corrects the
    rover plan §1.5, which inaccurately described Ball Butler as a
    Stewart-platform-style robot that catches.
2026-06-07 feat: add accuracy calibration analysis flow
    fit_affine.py pairs each ball landing to its commanded target by
    throw order (using the session metadata written by Jugglebot's
    ball_butler_node), transforms both into BB-local frame, and fits a
    2D affine measured_local → commanded_local — the direction
    ball_butler_node._apply_aim_correction consumes. Output JSON
    matches the existing throw_affine_correction.json schema (matrix +
    n_pairs + provenance) so dropping it into Jugglebot/.../resources/
    and launching with apply_aim_correction:=true is sufficient to
    enable it.
    Skips the manual cluster-mapping step from the old volley_viz.py
    workflow: pairing is unambiguous because the metadata JSON rec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
2026-06-10 Add validated throw aim-correction (fit tooling + deployed matrix)
    Fit a 2D affine aim-correction in BB-local frame from the 2026-06-09
    accuracy-calibration session (41 throw/landing pairs) and deploy it. A fresh
    32-throw validation session (correction live) cut mean aim error from 194.6 mm
    to 30.9 mm per cell (~84%), landing within 3 mm of the fit's own out-of-sample
    prediction.
    - fit_affine.py: order-pairs QTM landings to commanded throws, fits the affine,
    writes the matrix in the schema ball_butler_node consumes. (Includes a Python
    3.8 compat fix: str.removeprefix -> slice.)
    - throw_affine_correction.json/.png: the deployed matrix + fit visualisation.
    - throw_affine_correction_v2_res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
2026-06-10 chore: regenerate Teensy config headers from protocol_config.yaml
    Regenerated by config/generate_config.py (in the Jugglebot repo) after the yaml
    change:
    - protocol_config.h: mocap alignment gate 2.5/1.0 -> 2000/180 (matches the
    host-side relaxation; firmware does not gate on it, kept consistent anyway).
    - hardware_config.h: QTM_HOST 192.168.20.16 -> VR-Computer.local. Pre-existing
    drift (the yaml already specified VR-Computer.local; the committed header was
    stale) surfaced by regeneration, not a new decision.
2026-06-18 Resolve BB throw temporal accuracy (~140 -> <10 ms); firmware + tooling + logbook
    Closes the throw temporal-accuracy chapter (logbook 2026-06-10 -> 2026-06-18): end-to-end arrival error ~140 ms -> <10 ms. Spatial accuracy is handled by the aim-correction affine; temporal accuracy by a measured ~44 ms release-latency offset applied in ball_butler_node (Jugglebot). After the release-lag firmware fix, the residual proved to be a constant actuator latency -- not a launch-execution, feedforward, or kinematic-model error. Mocap kinematic system-ID and torque-feedforward root-fixes were both investigated and ruled out; see the 2026-06-18 entry for the full record and inline data.
    Firmware (ball_bu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
    [CanInterface.cpp, CanInterface.h, Trajectory.h]
2026-06-19 docs(logbook): add Chapter 1 — V0 Throw Accuracy synthesis (HTML)
    Add the first logbook "chapter": a self-contained, browsable HTML synthesis of
    the six-entry spatial + temporal accuracy campaign (2026-06-10 → 06-18). Covers
    the development, the key insights/developments, and the ranked open problems,
    with three hero plots and links down to each authoritative entry.
    Register Chapters as a documentation layer (answers the guide's "ask before
    inventing a layer" rule):
    - logbook/INDEX.md: new Chapters table above the entries
    - DOCUMENTATION_GUIDE.md: layer row (3b), subsection, and decision-tree bullet
    defining chapters as a non-authoritative synthesis that links down to entries
    Chapter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
2026-06-19 docs(logbook): chapter 1 review pass — dark mode, figure numbering, hot-launch re-test
    Address review comments on chapter 1:
    - Dark mode (default dark) with a persisted light/dark toggle; no-flash theme set
    before paint. Plot cards kept light so the white-background figures frame cleanly.
    - Stop framing "fracture the problem" as a durable takeaway — keep it as this case's
    solution (overview + subtitle reworded; removed from Key insights, renumbered).
    - New trajectory re-test of the "+3 deg / +10% hot launch" claim (Figure 4), with a
    reusable tool (plot_launch_geometry.py). Re-analysing the two clean 2026-06-17
    sessions (52 throws) from raw mocap, leaning only on latency/anchor-fr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
2026-06-19 docs(logbook): localise the launch-speed deficit (commanded->hand->ball), Figure 5
    Get to the bottom of the residual launch discrepancy using a 06-18 bag (16-36-14)
    that recorded the hand encoder, the mocap ball, AND the command together, so all
    three are on the same 51 throws:
    commanded C = 1.000
    hand peak H = 0.977 (servo under-track ~2.3%, R-independent rev/s ratio)
    ball B = 0.923 (net launch deficit ~7.7%)
    => B/H = 0.945 (hand->ball gap ~5.5%: effective spool radius and/or
    release transfer; not separable from this data)
    Verdict on the open question: the deficit is MOSTLY a hand->ball gap (~5.5%) with a
    minor servo shortfall (~2.3%)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
2026-06-19 docs(logbook): add 06-17-era speed chain (Figure 6) — the effect did not reverse
    Test whether the launch was genuinely "hot" at 06-17 and reversed since. Using the
    06-17 evening kinematic data (kinematic_obs.json, n=60):
    - Hand H/C = 0.976 — identical to 06-18's 0.977 (hand behaviour unchanged).
    - Encoder barrel angle = commanded (-0.04 deg).
    - Ball |v|/C = 1.044 when vz is read at the commanded throw_time (the 06-17
    method) -> "hot"; = 0.888 when read at the actual release (+44 ms) -> slow.
    So the machine did not change: the ball launched slow at both times. The "+hot"
    reading was vz evaluated 44 ms before the ball left (before gravity acted);
    removing that 44 ms flips the same thro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
2026-06-19 docs(logbook): fix the "not hot" justification — terse two-leg argument
    A review caught that the mocap "smaller parabola / apex" argument was presented as
    latency-independent, but apex/vz bake in the assumed 44 ms release instant (only the
    arc curvature -> vh is genuinely anchor-free). The absolute-apex vs init_pos comparison
    was also unreliable (init_pos is flagged "untruthful"; it required back-extrapolating
    the free-flight arc to before release) and made the story read as "peaks higher yet
    slower." Conclusion ("~7% slow, not hot") is unchanged — only the justification.
    Rewrite the hot-launch subsection to two anchor-clean legs:
    1. arc curvature => vh = 0.93x commanded => narrower a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
2026-06-21 docs(logbook): amend 06-17 & 06-18 entries — launch is ~7-8% slow, not hot
    Per the chapter-1 re-analysis, both entries carried a superseded reading of the
    residual launch error. Rather than bury the correction in a later entry, add a
    prominent AMENDED banner at the top of each (original reasoning left intact below,
    per the "don't destroy investigation history" rule):
    - 06-17: headline "+3 deg steeper / +10% hot" withdrawn; and the 06-18 note's
    "execution ~as-commanded" refined. The launch is ~7-8% slow at the commanded
    angle. Anchor-clean basis: mocap arc curvature => vh ~ 0.93x commanded
    (anchor-free); hand encoder => hand peaks 97.7% (ball can't beat the hand => not
    hot) + barre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
2026-06-21 build(pio): add teensy_loader_cli wrapper — fixes `pio run -t upload` + two-device-safe
    PIO's teensy-cli upload resolved teensy_loader_cli from PATH to the stale
    /usr/bin one (max TEENSY36, rejects imxrt1062), and passed -s (soft-reboot the
    first Teensy = two-device hazard). This wrapper (found via the existing
    scripts/bin PATH prepend) drops -s, reboots ONLY BB by USB serial into HalfKay,
    then delegates to /home/jetson/bin/teensy_loader_cli. Verified: pio run -t upload
    flashes BB cleanly.
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2026-06-22 test(firmware): instrument pitch-readiness for the Layer-A/C settle gates
    After the first hardware run aborted a Δ≈0 throw (C caught pitch not settled —
    pitch_done=0 while re-engaging CLOSED_LOOP), this build diagnoses the root cause
    before committing to a fix:
    - monotonic heartbeat stamp + axisHeartbeatMonoAgeUs() (sync-immune, mirrors the
    PV freshness pattern)
    - requestThrow logs pitch axis_state / trajectory_done / hb age / cur+tgt at queue
    - streamer C-check logs pitch axis_state + hb age on both abort and pass
    - pre-engage: requestThrow commands pitch+yaw at queue so re-engage/slew start ASAP
    - A re-engage reserve wired but DORMANT (PITCH_REENGAGE_RESERVE_S=0) — size it from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
    [BallButlerConfig.h, CanInterface.cpp, CanInterface.h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]
2026-06-23 test(firmware): name the binding axis in settle rejects/aborts + err; track-hold validation
    Firmware: A-reject and C-abort now name the limiting axis (PITCH/YAW/PITCH+YAW)
    and log the ODrive axis_error (err=0x..) — per operator request, to know which
    axis to speed up and to catch a fault. Test driver: replace single-park+idle
    (which let tracking time out -> pitch drifted to ~90deg stow before the throw,
    the run-1/2 abort artifact) with track_hold() continuous tracking so pitch stays
    CLOSED_LOOP on-aim, mirroring production.
    [HandTrajectoryStreamer.h]
2026-06-23 refactor(firmware): Phase-1 audit cleanup — strip diag, Layer-C freshness guard, drop pre-engage
    Post-validation /code-review cleanup (no correctness bugs found in the validated path):
    - strip the per-throw diagnostic prints (investigation scaffolding); the streamer
    'settled-confirm OK' was a raw Serial.printf on the fire path
    - Layer C: trust pitch trajectory_done only from a fresh heartbeat
    (hb_age < AxisSettleCfg::PITCH_HB_FRESH_US=300ms) so stale data can't confirm settled
    - drop the requestThrow pre-engage (redundant with executeThrow_; track-hold, not
    pre-engage, was the real fix)
    Kept the which-axis (PITCH/YAW) naming + err in the reject/abort messages.
    NOTE: built + reviewed;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
    [BallButlerConfig.h, HandTrajectoryStreamer.h]
2026-06-23 docs(logbook): close out Phase-1 settle-gates (validated 2026-06-23, status: tuned)
    Record the hardware validation (all 4 cases correct; both ACCEPTs threw, both
    REJECTs named the axis), the idle-gap root cause (test artifact, not the gate),
    the audit cleanup, and the open follow-ups (wind-up reserve approximation, dormant
    re-engage reserve, driver pass/fail). Phase 2 (loud-to-host channel) deferred.
2026-06-24 feat(firmware): Phase-2 loud command-outcome channel (CMD_RESULT) on BB
    Emit a CMD_RESULT (0x7D5) at every terminal point of a throw so a firmware-side
    reject/abort is reported to the host instead of silently dropped:
    - requestThrow rejects (bad state / no ball / no time-sync / Layer-A can't-make-
    lead, with the binding axis + lead shortfall),
    - executeThrow_ rejects (hand not homed / PV unavailable / PV stale / planner
    empty / exec-time lead / arm fail),
    - the Layer-C abort (ABORTED_NOT_SETTLED + binding axis + yaw error),
    - OK only at completion in handleThrowing_ (not at arm) — exactly one outcome
    per throw, never a premature OK if Layer C later aborts.
    New CanInterface::publishC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
    [BallButlerConfig.h, CanInterface.cpp, CanInterface.h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]
2026-07-29 feat(tooling): interactive design tool for the rover suspension
    Single-file browser tool for exploring the parallel-bar (parallelogram)
    suspension design space: sliders for geometry (L, h, x1, x2, wheel offset),
    load (mass, dynamic G-factor) and travel range drive an animated side view,
    stat tiles, and charts for spring length, motion ratio, spring force and
    pivot loads (incl. bar axial + bending at the spring pins).
    Corrects the hand derivation of the spring length. The correct form is
    s(theta) = sqrt(d^2 + h^2 - 2*h*d*sin(theta)), d = x2 - x1
    not sqrt(d^2 + (h/cos(theta))^2): the latter is symmetric in +/-theta and
    predicts stroke even when x1 == x2, where the true length is const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
2026-07-29 chore(config): resync generated hardware_config.h against Jugglebot YAML
    Pure codegen output (byte-identical to Jugglebot config/generated/), sweeping
    in the accumulated drift from already-committed Jugglebot-side config work
    that prior sessions never committed here. Enumerating so git blame never
    attributes these to an unrelated commit:
    - Dynamics: MOTOR_KT_NM_PER_A 0.0624 -> 0.057, new
    MOTOR_KT_ODRIVE_CONFIG_NM_PER_A + TORQUE_FF_* block (gravity FF arc)
    - ODriveDefaults: LEG_VEL_LIMIT_RPS 4 -> 12
    - Homing: new STOP_SETTLE_MS
    - JBOp: HAND_CATCH_PRIME_REV 9.858 -> 9.9594, new toss/reload block
    (TOSS_TIER 8b, TOSS_MAX_DISPLACEMENT_MM 150, TOSS_SESSION_* dwell/margin/
    max-throws, RELOAD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
2026-07-29 feat(endpoints): board+fw-qualified endpoint ids (lockstep w/ Jugglebot 386ade5)
    Jugglebot's protocol_config.yaml restructured its endpoints table into
    (board, fw)-qualified groups; the regenerated protocol_config.h here
    replaces the flat EndpointId constants with nested namespaces, and the two
    CanInterface.h aliases re-point at the S1 group:
    GPIO_STATES -> EndpointId::odrive_s1_0_6_11::get_gpio_states (700)
    COMMUTATION_MAPPER_POS_ABS -> EndpointId::odrive_s1_0_6_11::commutation_mapper_pos_abs (488)
    Values unchanged - BB's hand drive is an S1 0.6.11 where both ids are
    production-proven; only the names now carry the board+fw qualification.
    Build: pio run -e teensy41, run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
    [CanInterface.h]
2026-09-28 feat(firmware): firmware update over CAN - the Platform receiver ported to Ball Butler, with a safety park (lockstep w/ Jugglebot a229edd)
    `pio run -e teensy40_can -t upload` builds the image and hands it to Jugglebot's
    tools/teensy_link_bridge.py --fw-update --target bb, which streams it through the
    can-bridge's BB_FW_* relay (CAN1 0x7D6/0x7D7) into ball_butler_main/FwUpdate.cpp.
    - FwUpdate.{h,cpp}: the Platform Teensy's receiver, nearly verbatim (staging above
    the running image, per-sector read-back, CRC-32 + "ballbutler-main" identity at
    VERIFY, low-to-high interrupts-off copy + reset), plus OP_INFO (FW_VERSION = 1)
    as the version receipt.
    - Safety park before any flash (owner-agre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
    [BallButlerConfig.h, CanInterface.cpp, FwUpdate.cpp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]
2026-09-28 feat(firmware): FW 2 - the first Ball Butler image flashed over CAN (no code change; the version is the receipt) (lockstep w/ Jugglebot 4ad301b)
    Flown 2026-09-28: BB FW 1 over USB, --verify-only clean (61.0 s, 0 rewinds, BB
    rebooted on its 60 s idle timeout as designed), then pio run -e teensy40_can -t
    upload: VERIFY OK 0x25386A01, COMMIT OK, INFO "1 -> 2", 75.84 s, 0 rewinds; boot
    banner "ballbutler-main v2", homing OK, BOOT -> IDLE. The park's pitch-raise
    branch is still unexercised (pitch was stowed both times) - logbook follow-up.
2026-09-28 feat(firmware): FW 4 - no code change, receipt for the pipelined CAN transfer (3 -> 4 in 36.2 s) (lockstep w/ Jugglebot e9b7533)
    Can-bridge FW 22 deepened its RPC receive queue to 8, letting the host pipeline
    DATA 4 frames deep. BB FW 4 over CAN (pio run -e teensy40_can -t upload): DATA
    25.3 s, 0 rewinds/retries/missing acks, VERIFY OK 0x9A8BC5D5, COMMIT OK,
    "3 -> 4", 36.22 s total (first CAN flash this morning: 75.84 s). Receiver
    firmware unchanged.
2026-09-30 feat(firmware): FW 5 - the Layer C yaw settle confirm gains a 100 ms in-tolerance history term and a 12 deg/s traverse bound (built, NOT flashed) (lockstep w/ Jugglebot 08ec3fe6)
    At the Jugglebot R5 sitting on 2026-09-30 the gate refused 5 of 19 throws
    THROW_ABORTED_NOT_SETTLED with the yaw error inside the 1.0 deg tolerance
    (detail1 30/-18/-40/-47/-32 centideg): the settled axis's sigma-delta
    deadzone dither kicks 4+ encoder counts in one 150 Hz sample (or 2+2
    adjacent), which the 3.0 deg/s instantaneous rate term read as motion. A
    single-count flicker never tripped it (0.99 deg/s after the 0.3 EMA).
    Settled is now: |err| inside YAW_ERR_TOL_DEG for the last
    YAW_SETTLED_MIN_SAMPLES = 15 sam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
    [BallButlerConfig.h, HandTrajectoryStreamer.h, YawAxis.cpp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]
2026-09-30 docs(logbook): FW 5 flashed over CAN 2026-09-30 22:45 (receipt 4 -> 5); the pio upload hook needs repointing
    DATA 163840 B in 25.7 s, 0 rewinds / retries / missing acks, VERIFY OK
    crc32 0xF292D1C1, COMMIT OK, "Ball Butler FW version: 4 -> 5", driven by
    the Jugglebot skill-stack worktree's tools/teensy_link_bridge.py because
    platformio.ini's upload_command names the main checkout's copy, which is
    on a protocol-6 branch and dark against the protocol-9 bridge.
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2026-10-07 fix(calibration): extract real pilot flights (labelled ball, drag/tilt, apex occlusion)
    The 2026-10-07 hardware pilot extracted 0/10 throws. Diagnosis on the raw MCAP:
    - QTM gave the thrown ball rigid-body labels (Base - 1/3/4/7); the reader kept
    only empty-label markers. Read every marker; dedupe repeated frame stamps.
    - A gravity-only arc leaves 30-50 mm residuals over a 0.9 s flight (drag plus
    a ~1 deg effective-gravity tilt). Fit free constant acceleration, gated to
    6% of g, with the 8 mm / 5 mm RMS gates unchanged; measure the catch-plane
    XY from a local fit around the crossing.
    - The arc passes the predicted release point ~48 ms before nominal release and
    the ball is often oc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
2026-10-07 fix(calibration): judge mocap continuity by QTM stamps; carry on past bad captures
    A second pilot (run with a simultaneous QTM recording) stopped on "Mocap
    receive gap exceeded 100 ms" (0.102 s), but its bag shows <=13 ms receipt and
    <=21 ms QTM-stamp gaps. The guard timed the runner's own callbacks, which its
    ~23 ms session.json checkpoints (growing with the session) and a depth-5
    subscription stalled by 78-102 ms on every throw of both pilots; the full
    campaign would have tripped it regardless of QTM.
    - Depth-100 best-effort mocap subscription; StreamMonitor measures gaps from
    source stamps and flags backwards/zero stamps (QTM restart / clock reset).
    - A bad capture now rejects only tha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
2026-10-08 feat(calibration): solver guard, resumable sessions, safer refill prompt
    Pre-flight review of the full ~66 min campaign found no definite blocker but
    several ways to lose or silently corrupt it:
    - Solver: ~/.zshrc sources ~/Desktop/Jugglebot, the pilots imported
    Jugglebot-skills' throw_ballistics (different sha, 279 vs 277 feasible, up
    to 0.5 deg pitch). Print solver path/sha; --expect-solver-sha aborts on
    mismatch.
    - Resume: --resume-from SESSION_JSON (repeatable) skips entries already
    released and cleanly captured; plan/s/frame/solver must match. The analyser
    pools sessions (per-session BB pose, K:IDX exclusions).
    - Refill prompt flushes stray keystrokes and re-prompts on junk i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
2026-10-08 feat(calibration): re-send throws aborted by yaw NOT_SETTLED
    Full-campaign attempts on 2026-10-08 stopped on THROW_ABORTED_NOT_SETTLED
    (axis=YAW, -0.70/-0.83 deg error). The firmware aborts before any hand motion
    and keeps the ball; both bags show IDLE with ball_in_hand 0.16 s later.
    The runner now waits for readiness and re-sends the same entry (YAW or BOTH
    axis only) up to --max-attempts (default 3). Each send is its own row; an
    entry still unsettled is recorded in abandoned_throw_indices and skipped,
    and the session continues (--resume-from retries it). Every other refusal
    still stops the session. 36 tests pass.
2026-10-09 logbook: full local calibration after BB reinstall (candidate affine, pending validation)
    Session 20261009T002142_931068Z only (BB was reinstalled; earlier sessions
    invalid). 275/277 extracted; uncorrected 54.4 mm RMS, bias (+44, +9) mm,
    8% radial gain; affine predicted to reach ~21.8 mm per throw (core 21.3,
    the 20.7 mm repeatability floor). No drift; higher-order models no better.
2026-10-09 feat(calibration): hardware validation mode for a candidate correction
    --apply-correction maps each desired BB-local target through a candidate
    (as ball_butler_node would) and solves the command with the same positive s;
    targets stay the desired points, commands are recorded, out-of-region
    targets are skipped, and a candidate with a different s/frame/solver is
    refused. Resume and pooling refuse mixed corrections.
    Corrected sessions are analysable only with --extract-only, whose report
    now carries a PASS/FAIL/INCONCLUSIVE verdict against criteria fixed before
    the run (mean <=6 mm/axis, RMS <=26 mm all / <=25 mm core, enough throws).
    local_validation_plan.json (seed 1042, grid shifted half a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
2026-10-09 logbook: corrected validation result (accepted) and a behavioural solver guard
    Validation session 20261009T031319_612936Z: 110/110 corrected throws, per-throw
    RMS 21.0 mm (core 20.9), the predicted repeatability floor; mean (+1.6, -8.2) mm
    fails the pre-registered +-6 mm lateral check. The lateral mean is consistent in
    sign and size with the two sessions' BB pose calibrations differing by 0.47 deg
    in yaw offset (0.208 vs 0.681 deg; -8.0 mm at the 0.97 m mean range), which no
    matrix fitted in one session can remove. Owner decision 2026-10-09: accept and
    deploy, recorded as a deviation from the PASS requirement, with the pose
    calibration's yaw repeatability as the follow-up.
    run_local_calibra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
2026-10-10 fix(firmware): BB's own CAN input scales for its hand and pitch drives - FW 7
    FW 6 regenerated protocol_config.h from Jugglebot skill-stack, and
    CanInterface scaled set_input_pos vel_ff/tor_ff for every node by
    InputScale::hand_vel/hand_tor - Jugglebot's hand ODrive Pro keys, whose
    hand_tor is 1000 since Jugglebot FW 22. BB's hand S1 (node 8) is configured
    input_torque_scale 100 (odrive_s1_bb_hand_config.json; owner read 100 off
    node 8), so every hand torque feedforward went out 10x: pre-throw kicks,
    spinouts, 215 mm strokes, throws 7 % slow.
    - protocol_config.h regenerated from Jugglebot branch
    bb-own-input-scales-2026-10-10 (e0156a7d): only +InputScale::bb_hand_vel/
    bb_hand_tor (100/1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
    [CanInterface.cpp, CanInterface.h]
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2026-10-10 fix(firmware): SDO readback guard of the hand drive's CAN input scales - FW 8
    FW 6 sent the hand ODrive S1 (node 8, input_torque_scale 100) torque
    feedforward at Jugglebot's scale 1000. FW 7 gave BB its own scales; FW 8
    checks them against the drive at every hand arm.
    - protocol_config.h: regenerated from Jugglebot bb-s1-sdo-scale-guard-2026-10-10
    (b02c44e0); the diff is EndpointId::odrive_s1_0_6_11 only: can_input_torque_scale
    273, can_input_vel_scale 272, can_node_id 262, fw_version_* 10/11/12,
    hw_version_* 6/7 from the owner's S1 0.6.11-1 table, and
    commutation_mapper_pos_abs 488 -> 451 (488 is task_times.can_heartbeat.length
    there; never sent - isEncoderSearchComplete has no c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
    [CanInterface.cpp, CanInterface.h]
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
